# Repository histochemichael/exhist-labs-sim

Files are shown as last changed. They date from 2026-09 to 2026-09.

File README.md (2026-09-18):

# ExHist Labs Simulation

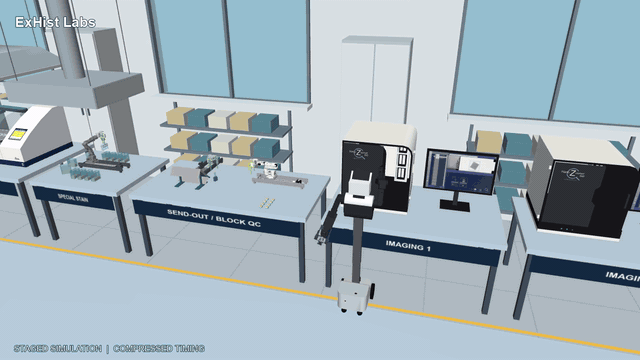
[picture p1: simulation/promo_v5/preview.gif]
ExHist Labs — looping 60-second lab promo


[Watch/download the full-quality video](simulation/promo_v5/ExHist-Labs-Promo-60s.mp4) · [Replay and QC details](simulation/promo_v5/README.md)

The preview loops through the full 60-second promo. If it is paused, check your
[GitHub animated-image settings](https://docs.github.com/en/account-and-profile/how-tos/account-settings/managing-accessibility-settings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).

A CAD-based histology laboratory in MuJoCo, with LeHisto stations, Nori A3, incubators, staining/coverslipping, scanning, and slide send-out/QC.

**Research simulation / development snapshot.** The live demo validates a bounded LeHisto rack loop. The promo is staged kinematic playback, not a physically validated autonomous lab.

## Browse by purpose

| Looking for | Open |
| --- | --- |
| Install, run, and tour every station | [Full illustrated guide](simulation/README.md) |
| Latest 60-second video and portable playback | [Revision 5: close-ups and continuous departure](simulation/promo_v5/) |
| Promo instructions and limitations | [Promo guide](simulation/docs/PROMO.md) |
| CAD STEP/STP and STL files | [CAD folder](simulation/cad/) |
| Static asset XMLs | [Asset models](simulation/models/assets/) |
| Station and asset pictures | [Image gallery](simulation/docs/images/) |
| Original/pinned source assets | [Source folder](simulation/source/) |
| Simulator mesh and texture assets | [Runtime assets](simulation/assets/) |
| Validation and distribution notes | [Validation record](simulation/docs/DISTRIBUTION_VALIDATION.md) |
| Repository organization | [Folder map](docs/REPOSITORY_LAYOUT.md) |
| Licensing and attribution | [License notice](simulation/LICENSE-NOTICE.md) |

## Run

From the repository root, using the documented Windows/Conda setup:

```powershell
cd simulation
conda env create -f environment.yml
conda activate exhist-sim
python tools/unpack_assets.py
python tools/check_install.py
python lab_rail_loop.py
```

After setup, `./launch.ps1` from the repository root starts the live demo. The viewer starts paused; press Space to run. See the full guide for controls and the separate Nori equipment-access environment.

The simulation bundle stays under `simulation/`, with the latest promo, portable
scene/playback, looping preview and scoped evidence grouped in `simulation/promo_v5/`.
Revision 5 includes the left parallel/right stock-claw swap, upright rack
transfers, gripper close-ups, smooth camera, supplied scanner screen and logo,
and Nori continuing away through the ending. The previous v4 bundle remains
available as history; the separate contact-tested live LeHisto demo is unchanged.

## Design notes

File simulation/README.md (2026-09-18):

# ExHist Labs Simulation

A CAD-based histology laboratory in MuJoCo: LeHisto sorting and special staining, Nori A3 handling, Quincy incubators, Leica staining/coverslipping, Hamamatsu scanning, and slide send-out/QC.

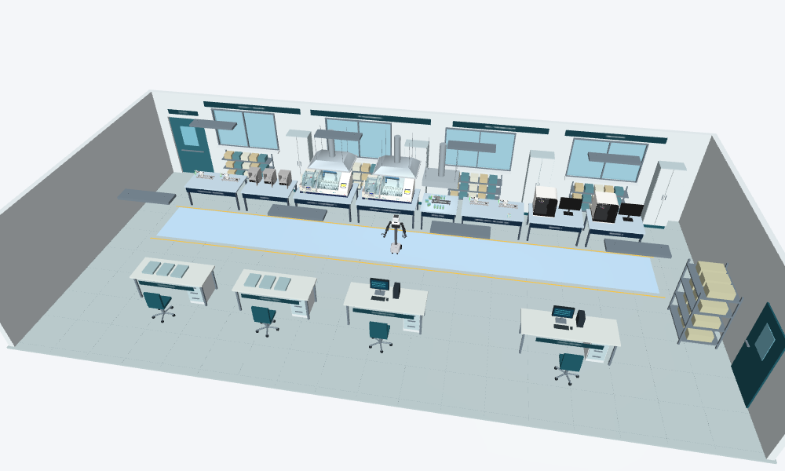
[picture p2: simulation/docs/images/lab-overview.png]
ExHist Labs — current complete room layout


**Research simulation / development snapshot. The full lab is not yet physically operational.** The current default demo runs the contact-driven, eleven-bath LeHisto rack loop in the complete room. Other stations and Nori are held visual context in that mode. No hardware commands are issued.

## Start here

- [Install and run](#install-and-run)
- [Station tour](#station-tour)
- [Asset gallery and downloads](#asset-gallery-and-downloads)
- [What is tested](#validation-and-limitations)
- [CAD and file conventions](docs/CAD_AND_ASSETS.md)
- [Licensing and attribution](LICENSE-NOTICE.md)

## Install and run

### Latest: 60-second promo with gripper close-ups

Watch the latest ExHist Labs promo

[Watch/download the 60-second MP4](promo_v5/ExHist-Labs-Promo-60s.mp4) · [Replay instructions and evidence](promo_v5/README.md)

In revision 5, Nori uses the original **right claw** for equipment access and the **left parallel gripper** for the upright rack. The loaded scanner, supplied PC screenshot, recorded LeHisto folder/sorting/staining work, top-right rack-handling close-ups and exact logo ending are included. Nori continues rolling away through the fade. The promo ovens have **120 mm extra upper clearance** as a modified concept, not stock Quincy dimensions. This is staged kinematic playback; see the scoped evidence and limitations in the promo guide.

The authored cut kept rack tilt below **0.018 degrees** and passed scoped geometric checks at all **1,800 frames**. This is **staged kinematic playback**, not a full-lab contact-physics result or proof of real slide retention. Fresh packaged checks and preserved author evidence are linked in the guide.

### Live laboratory scene

Windows 64-bit is the tested platform. Use **Python 3.10, MuJoCo 3.4.0 and PlaCo 0.9.20** for the live LeHisto loop. A desktop OpenGL-capable display/driver is needed for the viewer and screenshot rendering. Fusion is **not** required to run the simulation. No ROS, robot, camera or hardware connection is required.

Clone this repository (or download and extract its ZIP), then open a terminal in its `simulation/` directory. All commands in this guide run from that directory:

```powershell
conda env create -f environment.yml
conda activate exhist-sim
python tools/unpack_assets.py
python tools/check_install.py
python lab_rail_loop.py
```

The Conda environment gets the Windows PlaCo build from conda-forge. Other Python dependencies are pinned in [requirements.txt](requirements.txt). These versions were tested in an existing Windows environment; the environment file is a reproducible setup specification, not a claim of testing every fresh OS installation.

The viewer starts **paused**. Press **Space** to start/pause, **L** for LeHisto detail, **O** for the whole room, **1–8** for stations, and **+ / −** for playback speed. Close the window to exit. Initial loading can take a while because detailed CAD meshes are compiled.

PowerShell alternative, after activating the environment:

```powershell
./launch.ps1                       # live LeHisto loop
./launch.ps1 -Mode layout          # static/kinematic CAD inspection
./launch.ps1 -Mode hold            # readiness-hold view
```

If PowerShell blocks scripts, use the direct Python commands; changing system execution policy is unnecessary. The launcher uses the active environment's Python, not an author-specific installation path.

### Individual asset inspection

Each generated asset XML is a **static inspection model**, not a replacement for articulated machine physics. For example:

```powershell
python -m mujoco.viewer --mjcf models/assets/rack24.xml
```

### Nori equipment doors/drawers — separate environment

The original Nori access evidence used **MuJoCo 3.12.0 / Python 3.12**, not the live-loop engine. Keep these environments separate:

```powershell
conda create -n exhist-access -c conda-forge python=3.12 pip
conda activate exhist-access
python -m pip install -r requirements-access.txt
python tools/unpack_assets.py
python access_viewer.py --kind quincy
```

Kinds: `quincy`, `s60`, `st_load`, `st_unload`, `cv_load`, `ts_drawer`. These are **fixed-dock, actual-arm contact experiments**; the base is anchored and door/drawer dynamics are provisional. They are not complete mobile rack-transfer sequences. Keep the guards enabled.

### Headless checks

In `exhist-sim`:

```powershell
python tools/check_install.py
python -m unittest test_lab_rail_loop -v
python lab_rail_loop.py --validate
```

The last command reruns all eleven transfers and writes new `rail_loop_lab*.json` evidence. It may take several minutes or longer. It is not a whole-lab validation. Do not commit regenerated traces without inspecting the result. Existing files are versioned, so use a clean checkout or separate copy if preserving the packaged evidence matters.

### Troubleshooting

- **Missing file / compressed asset:** run `python tools/unpack_assets.py`. The script verifies SHA-256 and refuses to overwrite modified files. Large STEP/trace files are gzip-compressed to avoid normal GitHub file-size limits; Git LFS is not required.
- **Wrong MuJoCo version:** activate `exhist-sim` for the LeHisto loop, `exhist-access` for Nori access. Do not upgrade the physics engine and assume prior evidence still applies.
- **PlaCo import/DLL problem on Windows:** use the supplied Conda environment rather than assuming a Windows pip wheel exists. See [PlaCo installation documentation](https://placo.readthedocs.io/en/latest/basics/installation_pip.html).
- **OpenGL/display error:** use a local graphical desktop and working graphics driver. Headless rendering setup is platform-specific and is not bundled.
- **Pinned dependency/hash mismatch:** restore the matching repository revision or deliberately rebuild and revalidate. Do not disable integrity checks.
- **Neutral-pose adjacent-link warnings from PlaCo:** these are emitted by the imported IK model at initialization. The live loop has separate contact/failure guards; these messages are not a certification that all self-collisions are resolved.

## Station tour

These are actual renders of the packaged current model, not AI-generated concept images. The images show layout, not proof that every interaction works.

| Station | Purpose / equipment |
| --- | --- |
| Protocol sorting | Two LeHisto robots; protocol grouping and handled rack staging. |
| Baking | Three Quincy incubators. |
| Routine stain + coverslip 1 and 2 | Two Leica ST5020/CV5030 workstations with overhead canopies. |
| Special stain | One LeHisto, eleven matching containers, 25.4 mm inserts and canopy. |
| Send-out / block QC | Two LeHisto robots, slide folders and embedded cassette blocks. |
| Imaging 1 and 2 | Two Hamamatsu NanoZoomer S60 scanners with PCs. |
| Support / finished bench | Preparation, general work, documentation and digital-review bays. The general-work bench is the planned finished-folder destination. |

### Protocol sorting

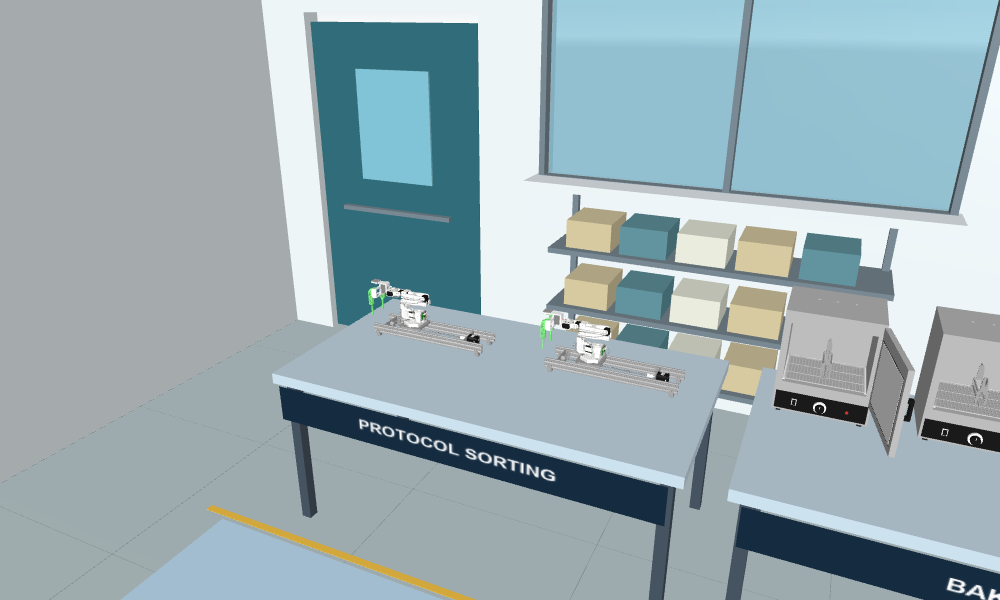
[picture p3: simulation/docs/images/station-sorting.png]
Protocol sorting station


Two LeHisto stations and rack staging. Populated-rack sorting and Nori handoffs are still under development.

### Baking

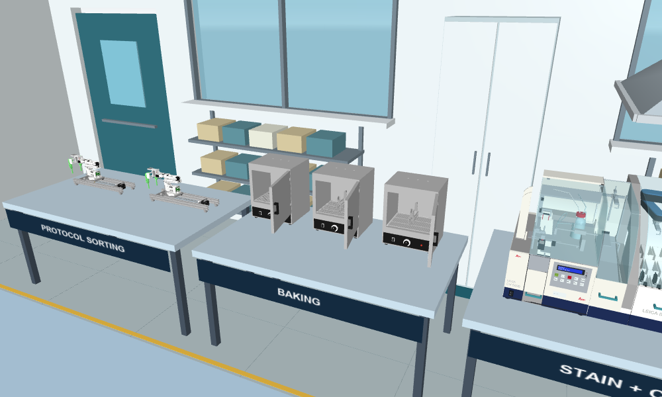
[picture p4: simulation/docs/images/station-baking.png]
Baking station


Three Quincy incubators. Doors are physical in isolated access tests; thermal processing is not modeled.

### Routine stain + coverslip 1

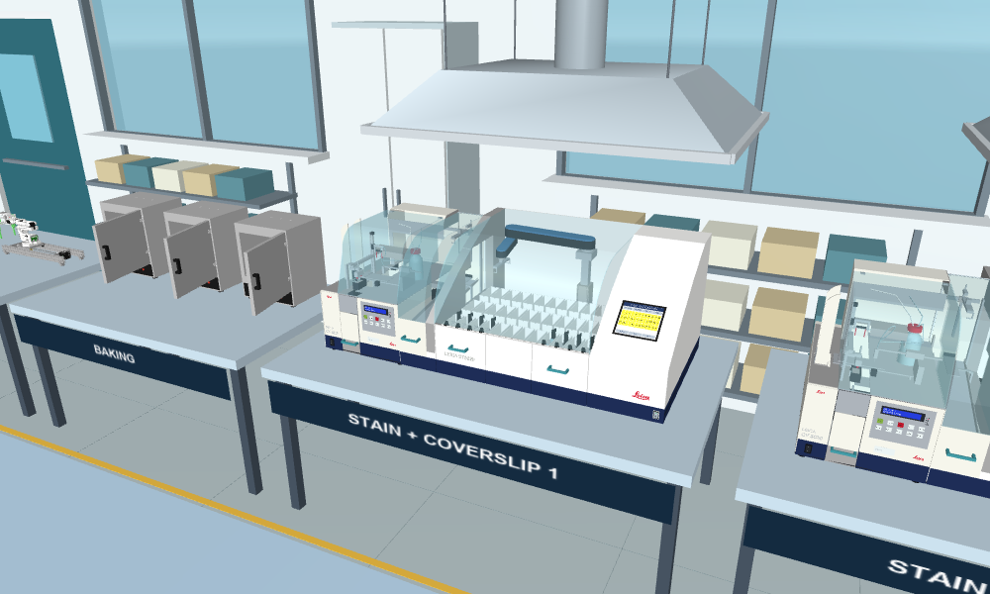
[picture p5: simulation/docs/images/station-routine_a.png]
Routine stain + coverslip 1 station


Leica ST5020/CV5030 workstation, access pulls and canopy. Inspection glazing lets the internals remain visible.

### Routine stain + coverslip 2

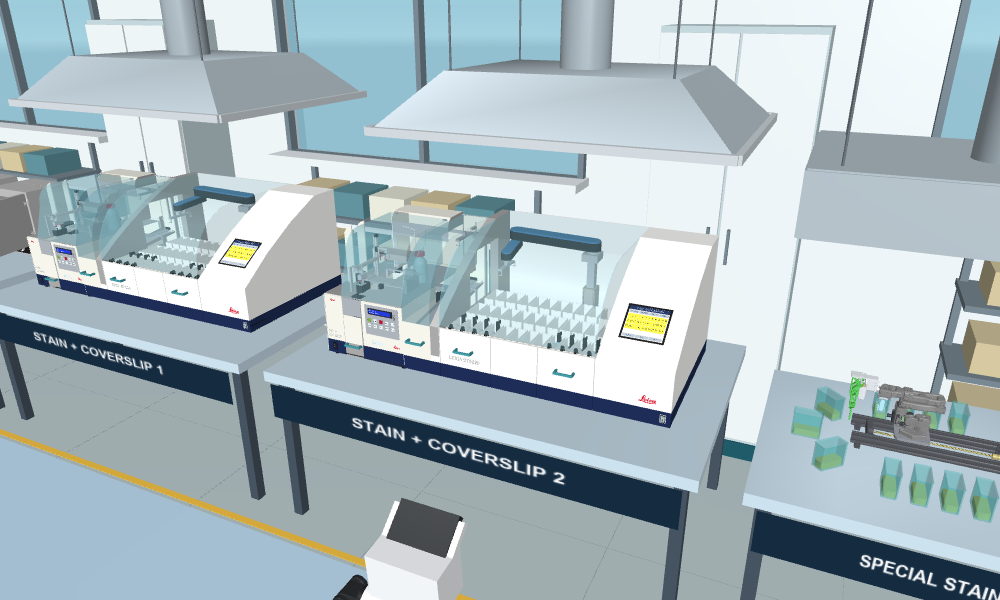
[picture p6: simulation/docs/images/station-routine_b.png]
Routine stain + coverslip 2 station


Second routine-processing bay. Internal articulation does not establish contact-validated payload transfer.

### Special staining

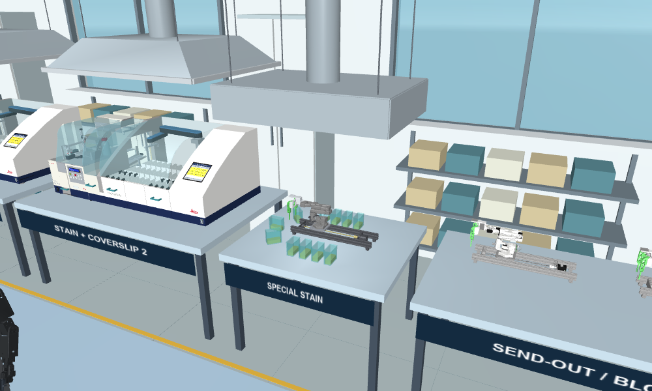
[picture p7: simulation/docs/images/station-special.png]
Special staining station


Live eleven-bath route: 1 → 2 → … → 11 → 1, original gripper, one-inch risers and bounded tabletop.

### Send-out / block QC

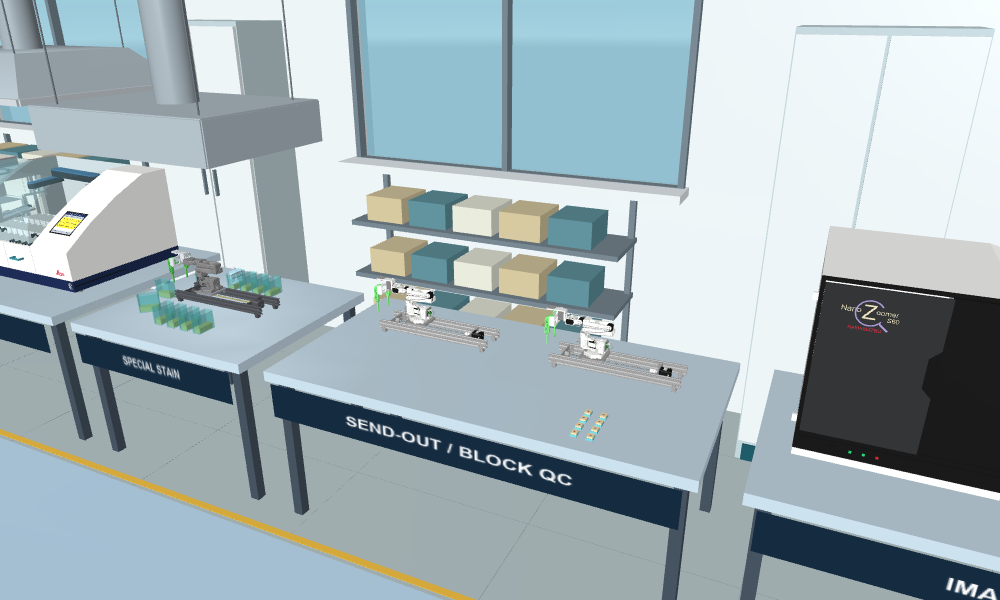
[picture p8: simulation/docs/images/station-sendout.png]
Send-out / block QC station


Two LeHisto arms, folder workspace and cassette-block QC. Folder loading/closing/carrying is not yet physically validated.

#### New: 45-degree QC folder cradle (selectable layout)

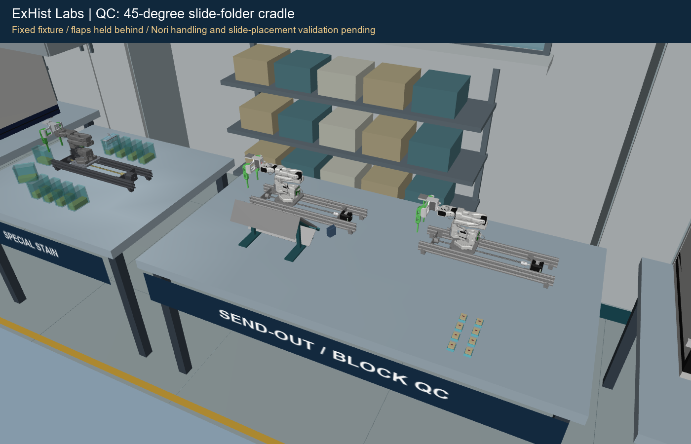
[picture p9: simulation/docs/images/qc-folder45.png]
QC folder cradle in the lab


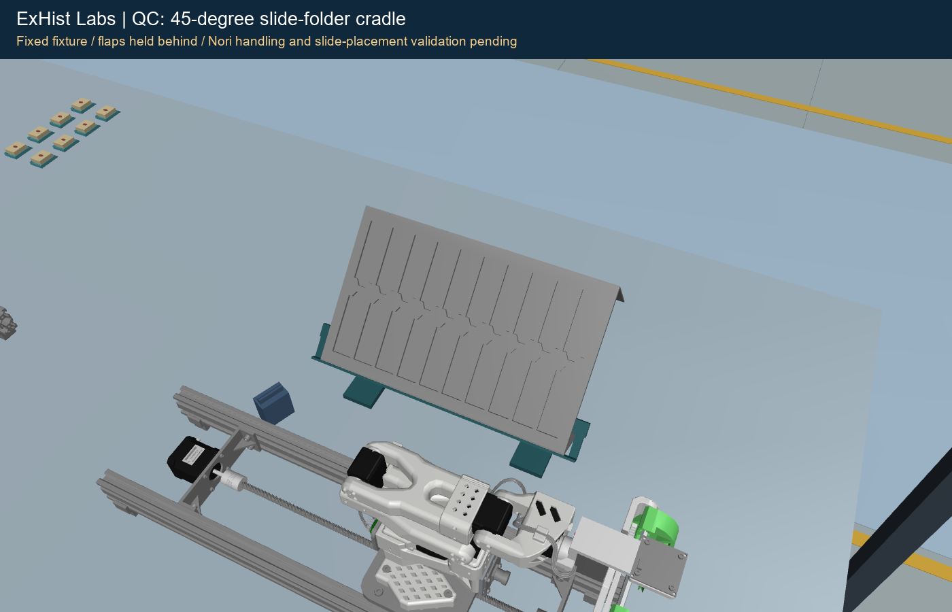
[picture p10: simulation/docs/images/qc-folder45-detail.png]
Folder pockets viewed from the LeHisto side


The pinned concept places a 20-pocket folder on a fixed, 45-degree presentation cradle in front of the left QC LeHisto. Its cover flaps are held behind the tray; the feet sit on the 800 mm bench. Empty side-access volumes are reserved for Nori's left arm, but are **not certified gripper envelopes**. No second Nori has been added. Nori need not continuously hold the folder in this fixture concept.

```powershell
python qc_folder_cradle.py                    # held whole-lab QC inspection
python lab_rail_loop.py --qc45                # live special-stain loop + held QC layout
python qc_folder_cradle.py --check            # scoped static layout checks
python -m unittest test_qc_folder_cradle -v
```

Press **6** in the live-loop viewer for QC. This optional composition preserves the existing tested base XML and historical evidence. The new 45-degree slide-placement controller is still being tested separately and is **not imported or claimed passed**. Passive folder docking, Nori reach/grasp/transfer, fasteners, stiffness, stability, flap closing and loaded retention remain unvalidated.

[Layout and assumptions](docs/QC_FOLDER45.md) · [stand STL, mm](cad/stl/Folder-Stand-45-Assembly.stl) · [standalone folder/cradle XML, m](models/assets/qc_folder45.xml) · [scoped check results](qc_folder45_validation.json)

### Imaging 1

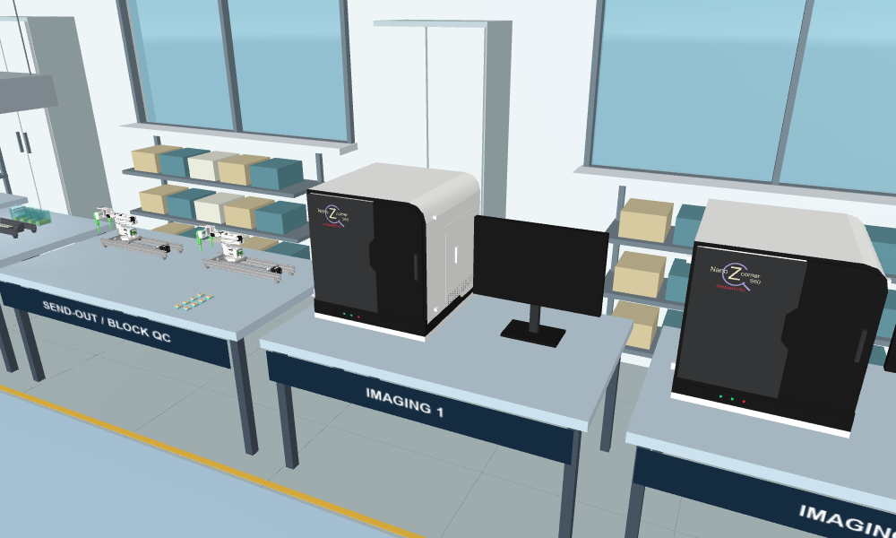
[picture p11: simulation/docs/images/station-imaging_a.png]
Imaging 1 station


NanoZoomer S60 and PC; scanner cassette interfaces and Nori insertion need further integration.

### Imaging 2

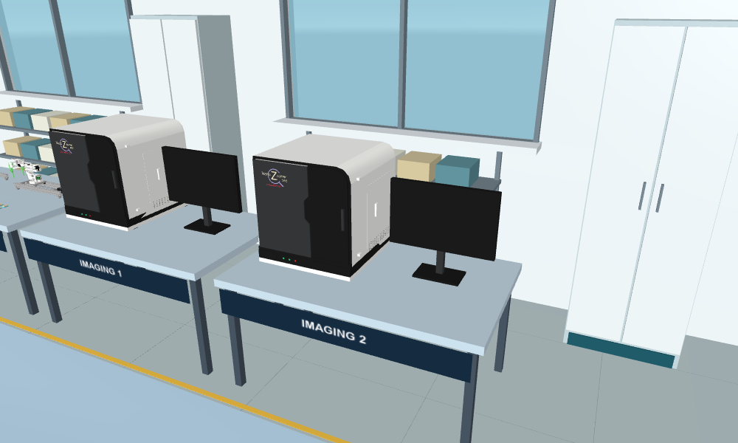
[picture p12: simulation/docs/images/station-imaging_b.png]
Imaging 2 station


Second scanner and PC with the same development limitations.

### Nori A3 and the surrounding lab

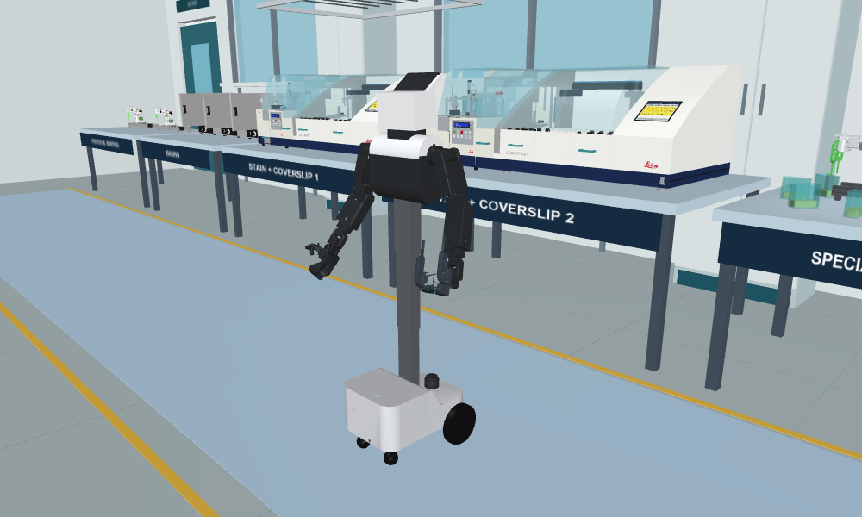
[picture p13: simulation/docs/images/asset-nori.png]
Nori A3 in the current laboratory stance


The historical base environments retain the stock left claw and parallel histology gripper on the other arm. **The latest [v5 promo scene](promo_v5/scene.xml) swaps these: left parallel tool, right stock claw.** Its raised inspection posture keeps the shoulders above the 800 mm benches. Gripper grooves are user-tested hardware geometry; complete contact-force grasp/transfer validation remains separate. Nori’s original source model is [bundled here](source/nori/Nori%20with%20parallel%20histo%20gripper.xml), with [mesh files](assets/nori) and [license/limitations](licenses/nori/NOTICE). **No Nori STEP manufacturing CAD was supplied; none is fabricated from these meshes.**

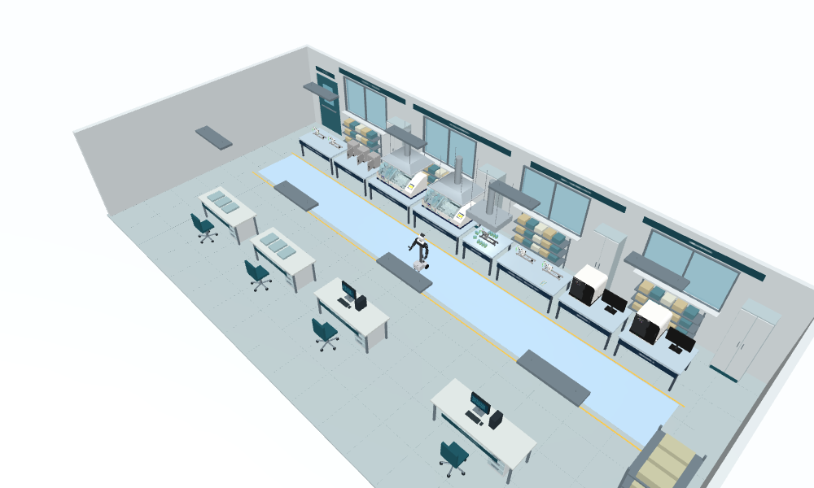
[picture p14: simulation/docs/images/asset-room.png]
Cabinets, shelves, work bays, chairs, doors, windows and PCs


The architectural context includes four windows, two doors, four tall cabinets, five shelving bays, four extra work tables, four chairs and two additional PCs. The eight process benches, hoods, aisle markings, furniture and signage are procedural geometry in [lab_room.py](lab_room.py), [build_scene.py](build_scene.py), and the main XMLs. They are static scene props; door swing, furniture mechanics and fume extraction are not validated. Canopies are layout concepts, not ventilation designs.

## Asset gallery and downloads

**STL exports below use millimetres; MuJoCo XML/OBJ geometry uses metres.** Original robot STLs keep their original scales, specified in their XML/URDF; do not apply the catalogue STL scale indiscriminately. Native CAD assemblies and simulation tessellations are different deliverables. See [CAD provenance and conventions](docs/CAD_AND_ASSETS.md).

### LeHisto v38

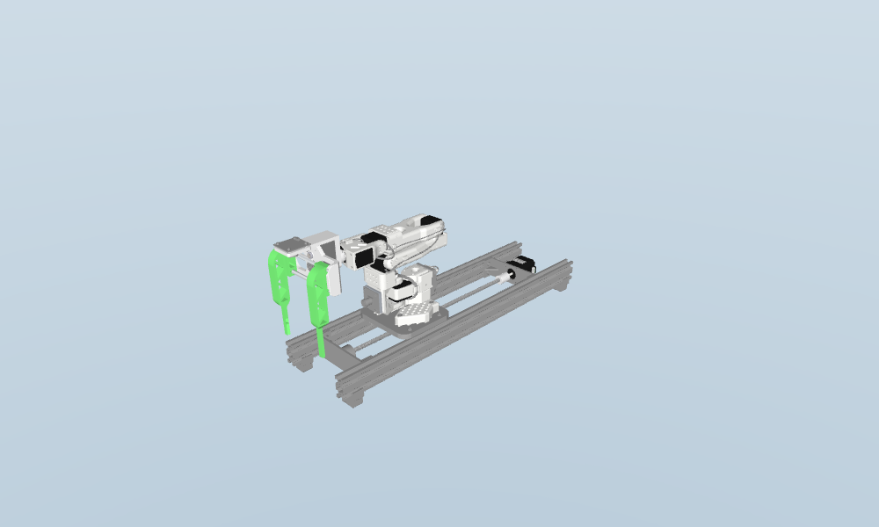
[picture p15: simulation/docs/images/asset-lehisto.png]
LeHisto v38


Rail-mounted SO-101 arm with the printed dual-groove slide/handle gripper and cameras.

[STL](cad/stl/lehisto.stl) · [Asset XML](models/assets/lehisto.xml) · [Source tessellation](assets/lehisto.json) · [STEP/STP](cad/step/lehisto-v38.stp)

### Quincy 10GC incubator

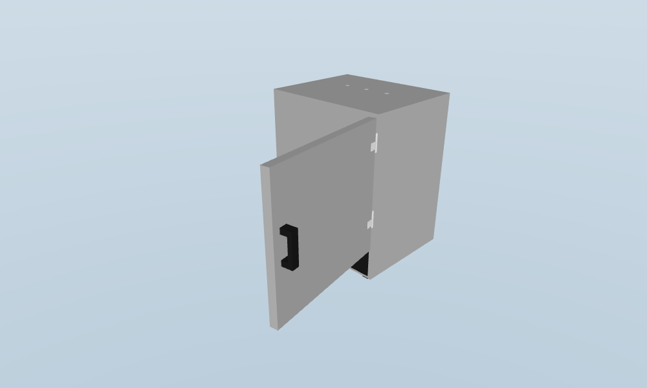
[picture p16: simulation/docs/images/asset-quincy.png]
Quincy 10GC incubator


Baking enclosure and swing door. Three instances sit on the baking bench.

[STL](cad/stl/quincy.stl) · [Asset XML](models/assets/quincy.xml) · [Source tessellation](assets/quincy.json) · [STEP/STP](cad/step/quincy-10gc.stp)

### Leica ST5020 + CV5030

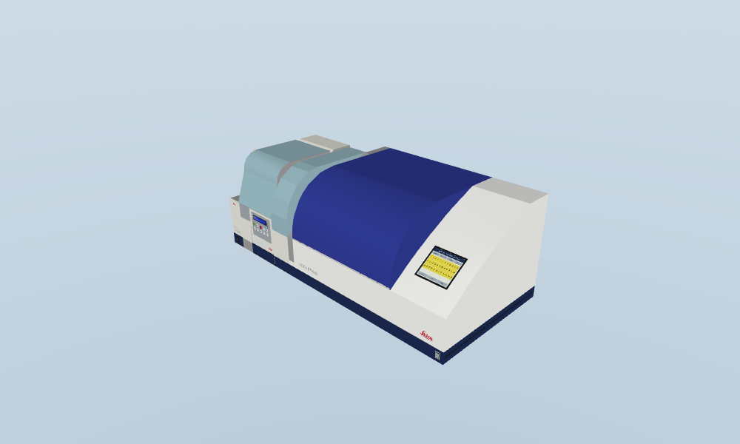
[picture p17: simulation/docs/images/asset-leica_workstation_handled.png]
Leica ST5020 + CV5030


Stainer, coverslipper and transfer station. CAD articulation and estimated internals are retained; transparent lids are a simulation inspection setting.

[STL](cad/stl/leica_workstation_handled.stl) · [Asset XML](models/assets/leica_workstation_handled.xml) · [Source tessellation](assets/leica_workstation_handled.json) · [STEP/STP (gzip)](cad/step/leica-workstation.stp.gz)

### Hamamatsu NanoZoomer S60

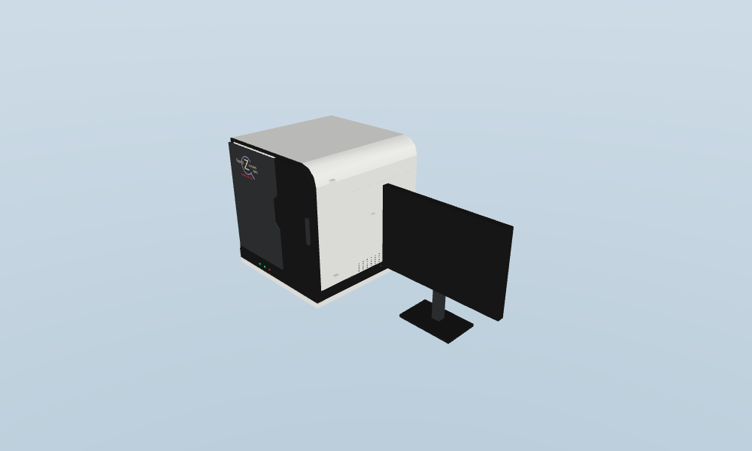
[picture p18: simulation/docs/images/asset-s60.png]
Hamamatsu NanoZoomer S60


Branded scanner assembly and PC. Scanner depth and carrier interfaces remain provisional.

[STL](cad/stl/s60.stl) · [Asset XML](models/assets/s60.xml) · [Source tessellation](assets/s60.json) · [STEP/STP](cad/step/nanozoomer-s60.step)

### 24-slide handled rack

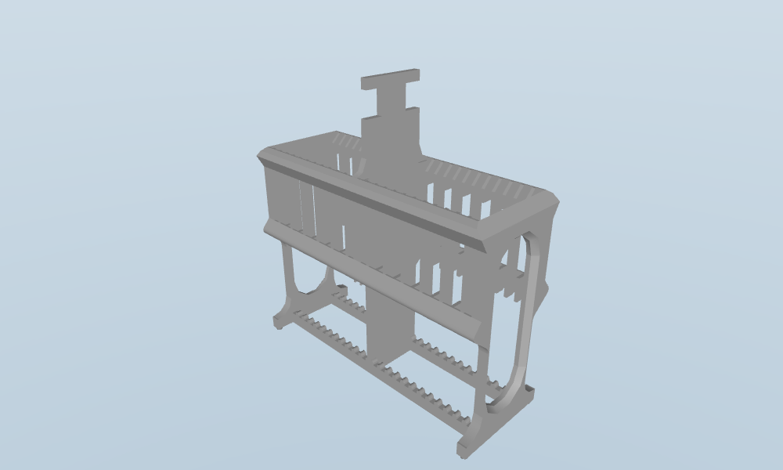
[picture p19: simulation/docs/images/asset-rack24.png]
24-slide handled rack


User-tested handle geometry; not interchangeable with the Leica or scanner carriers.

[STL](cad/stl/rack24.stl) · [Asset XML](models/assets/rack24.xml) · [Source tessellation](assets/rack24.json) · [STEP/STP](cad/step/slide-rack-24-with-container.stp)

### Matching 24-slide container

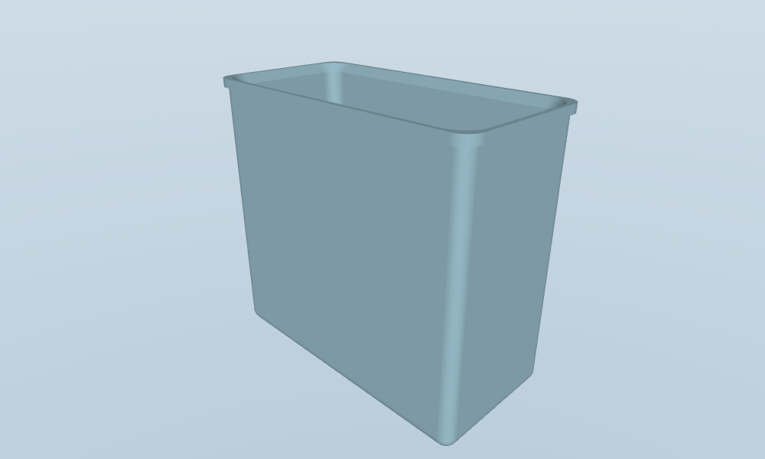
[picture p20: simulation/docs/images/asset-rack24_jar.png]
Matching 24-slide container


Actual companion vessel for the rack; eleven are arranged around the special-staining rail.

[STL](cad/stl/rack24_jar.stl) · [Asset XML](models/assets/rack24_jar.xml) · [Source tessellation](assets/rack24_jar.json) · [STEP/STP](cad/step/slide-rack-24-with-container.stp)

### 25.4 mm container insert

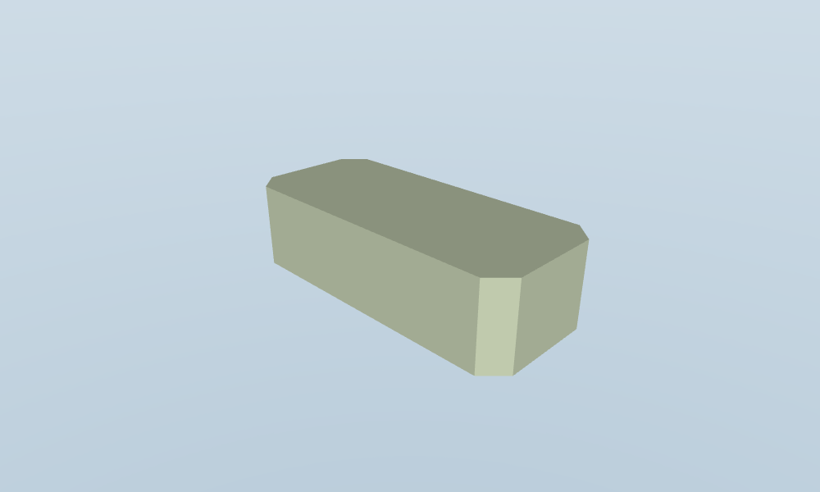
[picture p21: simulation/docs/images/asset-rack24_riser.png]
25.4 mm container insert


Removable one-inch support block. Material, fluid compatibility and immersion depth are unvalidated.

[STL](cad/stl/rack24_riser.stl) · [Asset XML](models/assets/rack24_riser.xml) · [Source tessellation](assets/rack24_riser.json) · [Parametric source](assets/rack24_riser_25p4mm.scad)

### Handled Leica staining rack

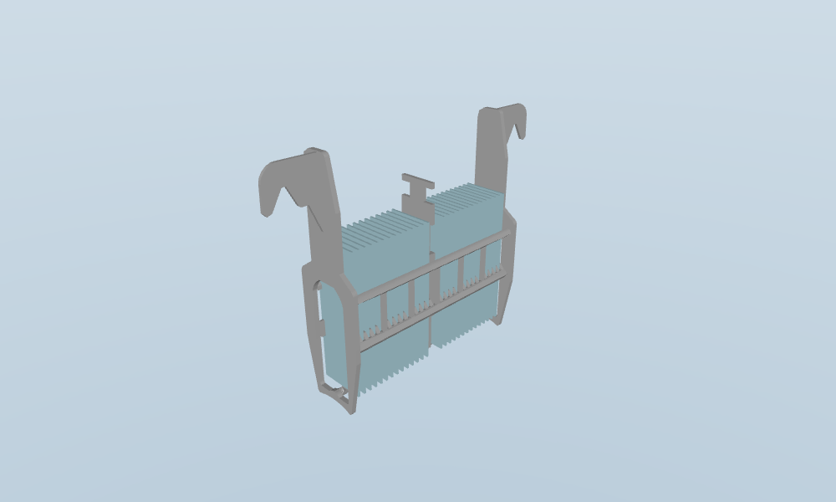
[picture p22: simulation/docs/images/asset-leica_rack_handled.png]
Handled Leica staining rack


Updated input rack with carrying handles. Native export captures the open Fusion document, including its unsaved local state.

[STL](cad/stl/leica_rack_handled.stl) · [Asset XML](models/assets/leica_rack_handled.xml) · [Source tessellation](assets/leica_rack_handled.json) · [STEP/STP](cad/step/leica-rack-handled.stp)

### CV5030 30-position output magazine

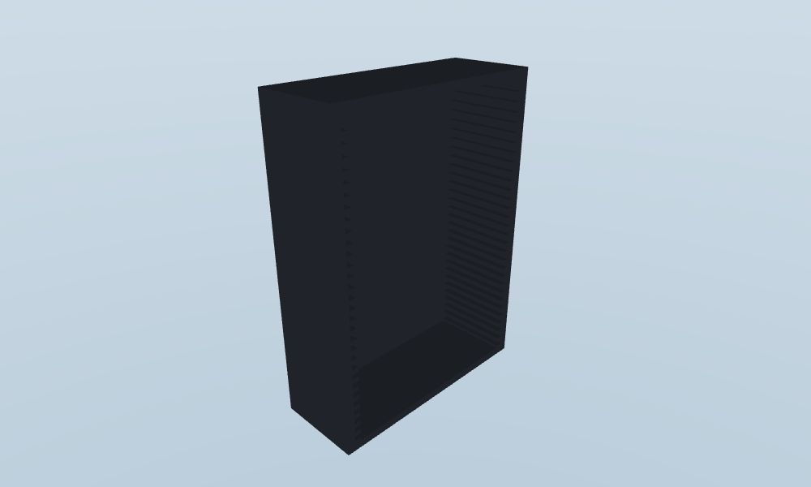
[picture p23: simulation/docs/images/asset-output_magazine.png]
CV5030 30-position output magazine


Output carrier for coverslipped slides. Automated removal and populated slide exchange are unfinished.

[STL](cad/stl/output_magazine.stl) · [Asset XML](models/assets/output_magazine.xml) · [Source tessellation](assets/output_magazine.json) · [STEP/STP](cad/step/cv5030-output-magazine-30.step)

### Scanner cassette

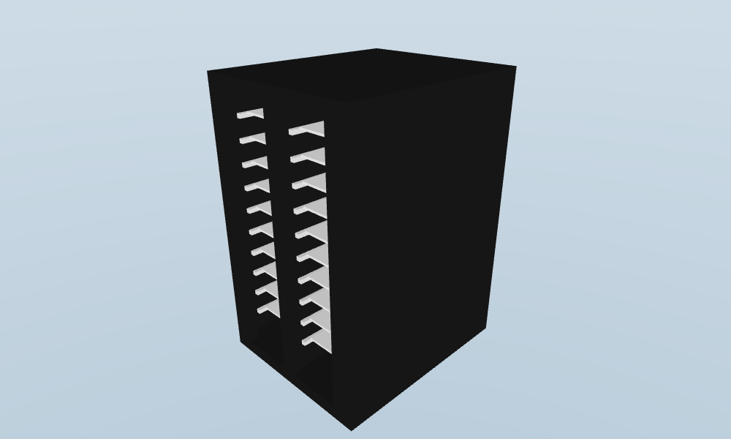
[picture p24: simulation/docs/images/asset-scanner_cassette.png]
Scanner cassette


S60-specific carrier. Its depth is explicitly provisional; this export does not establish slide/gripper clearance.

[STL](cad/stl/scanner_cassette.stl) · [Asset XML](models/assets/scanner_cassette.xml) · [Source tessellation](assets/scanner_cassette.json) · [STEP/STP](cad/step/scanner-cassette-provisional.stp)

### 20-place slide folder

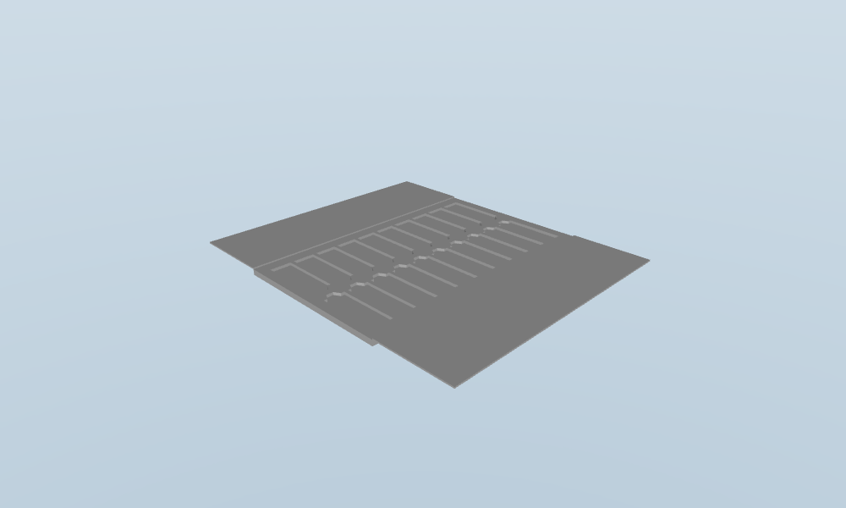
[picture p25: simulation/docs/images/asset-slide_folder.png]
20-place slide folder


Cardboard folder and cover flaps. Physical folding, loaded retention and left-hand transport remain unfinished.

[STL](cad/stl/slide_folder.stl) · [Asset XML](models/assets/slide_folder.xml) · [Source tessellation](assets/slide_folder.json) · [STEP/STP](cad/step/slide-folder-20.stp)

### Embedded cassette block

Embedded cassette block

Cassette, paraffin and tissue geometry for the block-QC work surface.

[STL](cad/stl/cassette_block.stl) · [Asset XML](models/assets/cassette_block.xml) · [Source tessellation](assets/cassette_block.json) · [STEP/STP](cad/step/embedded-cassette-block.step)

### Grippers, handles, slides and coverslips

Original gripper handle groove contact inspection

The top finger groove receives rack handles; the lower groove receives slides. The detailed LeHisto gripper/rail source meshes and joint descriptions are in [rail_loop_reference/source/robot](rail_loop_reference/source/robot). Nori's attachment meshes are in [assets/nori](assets/nori). [Drawer pulls v02](cad/step/drawer-pulls-v02.step) and the [Quincy stand-off pull](cad/step/quincy-pull-v01.step) are **unbuilt concepts**, not approved machine modifications. Slides, coverslips, support surfaces and fixture/contact proxies also appear as procedural geoms in the XMLs. The loaded rack in the current eleven-bath loop uses fixed slide visuals, **not individually free glass**.

### Procedural room asset kit

Bench, canopy, cabinet, shelf, chair, PC, entry door and window close-ups

These representative pieces are exported from the actual scene geometry. They are static visual models, not fabrication designs or mechanically validated furniture.

| Asset | STL | XML |
| --- | --- | --- |
| Process bench | [STL](cad/stl/bench.stl) | [XML](models/assets/bench.xml) |
| Special-stain canopy | [STL](cad/stl/canopy.stl) | [XML](models/assets/canopy.xml) |
| Storage cabinet | [STL](cad/stl/cabinet.stl) | [XML](models/assets/cabinet.xml) |
| Shelf bay and boxes | [STL](cad/stl/shelves.stl) | [XML](models/assets/shelves.xml) |
| Task chair | [STL](cad/stl/chair.stl) | [XML](models/assets/chair.xml) |
| PC workstation | [STL](cad/stl/pc.stl) | [XML](models/assets/pc.xml) |
| Entry door | [STL](cad/stl/entry-door.stl) | [XML](models/assets/entry-door.xml) |
| Observation window | [STL](cad/stl/window.stl) | [XML](models/assets/window.xml) |

## Files and data

| Location | Contents |
| --- | --- |
| `exhist_rail_loop.xml` | Current complete-room model with live special-stain station and held lab context. |
| `exhist_operational.xml` | Articulated development scene / readiness workbench. |
| `exhist.xml` | Static/kinematic lab inspection layout. |
| `assets/` | Actual mesh, texture, tessellation and kinematic assets used by the lab. |
| `models/assets/` | Individual static asset XML viewers and their meshes. |
| `cad/step/` | Native STEP/STP exports; large workstation file is losslessly compressed. |
| `cad/stl/` | Consolidated millimetre STL exports of the catalogued CAD assets. |
| `source/` | Bundled source Nori XML and mesh dependencies. |
| `rail_loop_reference/` | Pinned reference controller, URDF, scene, meshes and evidence. |
| `docs/images/` | Rendered station/asset gallery. |
| `docs/portability-validation.json` | XML-parameter and compiled-dynamics comparison after path relocation. |
| `docs/DEVELOPMENT_HISTORY.md` | Historical author notes; older claims/launch paths do not override this README. |

Authoring/export scripts remain for provenance and development. Some historical Fusion/film/rebuild helpers refer to the author's external projects and are **not portable entry points**. Running the delivered XMLs and documented viewers does not require those external projects. Do not blindly regenerate source snapshots from other tasks.

## Validation and limitations

The packaged copy passed a fresh **11/11 transfer run** and **20 targeted regression tests**. See [distribution validation](docs/DISTRIBUTION_VALIDATION.md) for versions, measurements and scope.

The original lab loop completed all eleven contact-driven rack transfers. A fresh packaged-copy run and its scope are recorded in [rail_loop_lab_validation.json](rail_loop_lab_validation.json). [LAB_RAIL_LOOP_RESULTS.md](LAB_RAIL_LOOP_RESULTS.md) describes the original integration evidence, including its export-recovery provenance. [STABILITY_VALIDATION.md](STABILITY_VALIDATION.md) describes separate fixed-dock access/passive-object tests. Those are distinct experiments, not an end-to-end lab acceptance test.

The portability check compares all non-path XML parameters and 420 numerical model arrays per model. Resource-path buffers and MuJoCo-derived convex-hull representation differences are reported separately. No controllers, joint limits, physical forces or contact rules were relaxed to package the demo.

**Still unfinished:** coordinated Nori navigation/docking and handoffs; populated carrier exchange; CV5030 output-rack extraction; scanner insertion/removal; complete physical folder loading, closing and transfer; room-wide collision coverage. Fluids, chemistry, glass breakage, optical scanning, medical performance and hardware safety are not validated.

This repository is a development workbench, **not** a turnkey autonomous lab, learned policy, manufacturer-certified digital twin, medical device, or authorization to operate equipment.

[Licensing / attribution / noncommercial Nori restrictions](LICENSE-NOTICE.md)

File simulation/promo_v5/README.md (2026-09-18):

# ExHist Labs promo — revision 5

Looping 60-second promo

[Watch/download the full-quality MP4](ExHist-Labs-Promo-60s.mp4) — 60 seconds,
1280 × 720, 30 fps. The GIF loops indefinitely; GitHub may pause animated images
when a viewer has reduced-motion or autoplay-disabled settings.

## What's in this revision

- Left parallel slide/rack gripper; original right claw for doors and drawers.
- Loaded scanner with 60 individual slide meshes and the supplied PC screenshot.
- Recorded LeHisto folder placement, slide sorting and special-stain background work.
- Upright oven-to-stainer rack transfer; oven and drawer close afterward.
- Fading top-right close-ups of rack pickup and stainer placement/release.
- Stainer fork deposits into the first rear vessel; Nori keeps rolling away
  through the fade into the supplied teal/black logo.

## Replay locally

Use the repository's documented Windows `exhist-sim` environment (MuJoCo 3.4.0),
then from `simulation/`:

```powershell
python promo_v5/render.py --check
python promo_v5/render.py
```

The second command writes `promo_v5/rerendered.mp4`; it does not overwrite the
published video. Desktop OpenGL is required. All scene resources are repository
relative; no author workspace, camera connection or hardware is needed.
`playback.npz` contains the exact 1,800 output-time joint/mocap/background poses
and both cameras, not a controller or training policy. Existing STEP/STL source
assets remain under `../cad/`, `../assets/` and `../source/`.

## Evidence and limits

- [Original sampled geometry audit](evidence/author-sequence-solid-audit.json):
  zero unintended intersections in its scoped 1,800-frame checks; maximum
  loaded rack tilt 0.008287 degrees.
- [Tool-swap audit](evidence/author-swap-mechanics-audit.json): original joint
  limits, mount frames, printed grooves and jaw coupling preserved.
- [Packaging equivalence](evidence/portability.json): resource paths changed,
  but compiled geometry, joint and inertia arrays match the author model.
- [Packaged replay check](evidence/packaged-render-check.json): rendered-frame
  comparisons, MP4 duration, GIF duration and indefinite-loop metadata.
- [Author delivery verification](evidence/author-delivery-gripper-closeups-rollaway-verification.json).

**Staged kinematics / compressed timing, not physically validated autonomy.**
Objects use prescribed poses/attachments. These checks do not certify grasp
forces, slip, actuator torque/speed, wheel-contact dynamics, passive-door forces,
whole-room continuous collision avoidance, hardware safety or actual throughput.
The oven is a user-authorized taller simulation concept (+120 mm upper headroom),
not manufacturer-certified dimensions or an updated manufacturing STEP.
Background folder work replays one previously tested pocket placement, not a
complete 20-slide folder. Original author reports are preserved as provenance;
they are not relabeled as newly executed packaged physical tests.

The prior v4 bundle remains available at `../promo_v4/` for history.

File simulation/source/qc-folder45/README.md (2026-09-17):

# Pinned Final QC Inputs

Copies from LeHisto commit d6da8e09789b35e5a1595b4da6a9ddd3871c7cfe (2026-09-16). Final folder center [0.026, -0.240, 0.075] m, 45-degree tray, covers held 100 degrees behind. Source holder [0.240, -0.100, 0.0127] m at 67.38-degree yaw.

`folder45.py` is builder provenance only; imports are not packaged to run here. `folder_slide_45.xml` contributes only the fixed folder, stand and source-holder geometry. `folder_stand_45.json` defines the ten-body stand. `slide_folder.json` is the original CAD tessellation.

Matching stand STEP, Fusion archive and millimeter STL are in `../../cad`. Hashes are recorded in `../../qc_folder45_layout.json`. LeHisto's standalone one-pocket dynamics passed; this lab integration is static context only, not Nori or lab slide-placement validation. Do not run the source builder to mutate another task.

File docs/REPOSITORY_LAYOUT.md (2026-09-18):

# Repository layout

The top level is a short entry point rather than hundreds of development files.

```text
README.md              Start here: downloads, gallery, installation
launch.ps1             Launch from the repository root
docs/                  Repository navigation and organization checks
simulation/            Self-contained simulation and historical evidence
  README.md            Full illustrated station guide and commands
  cad/                 STEP/STP, STL and native design assets
  models/assets/       Standalone static inspection XML models
  assets/              Runtime meshes and textures
  source/              Pinned source models and component provenance
  licenses/            Upstream license notices
  docs/                Station images, asset catalog, validation guides
  promo_v5/            Latest MP4, looping GIF, portable scene/playback and evidence
    background-assets/ Recorded folder-rig meshes
    evidence/          Author provenance and packaged replay verification
    images/            A few selected review frames
  promo_v4/            Historical promo, playback and scoped evidence
  rail_loop_reference/ Pinned LeHisto loop implementation and data
  tools/               Installation, unpacking and publication utilities
```

The loose files formerly at the root are now inside `simulation/`. Its Python modules, scene XMLs and historical output files intentionally retain their relative positions in this first organization pass: many experiments load neighboring traces and models by name. This avoids rewriting tested simulation behavior merely to change GitHub's landing page.

## Existing command migration

Run existing guide commands **from `simulation/`**, or use the new root launcher. All links within the full illustrated guide remain relative to that bundle. No CAD geometry, trace, model or video was regenerated for this move.

For example:

```powershell
cd simulation
python tools/unpack_assets.py
python -m unittest test_lab_rail_loop test_qc_folder_cradle -v
```

The root `.gitignore` excludes restored large assets at their new locations. Tracked gzip archives and their SHA-256 manifest remain inside the simulation bundle. Use `simulation/tools/unpack_assets.py` to restore them, not Git LFS.

## Organization checks (2026-09-17)

- Before documentation updates, all 1,977 relocated tracked files matched the Git blob hashes from `df662f0` exactly. No simulation code, CAD, XML, image, video or trace changed.
- All four compressed assets restored/verified against their existing SHA-256 manifest.
- Three main MuJoCo scenes compiled, and the live LeHisto controller initialized successfully from the new location.
- All 13 existing loop/QC regression tests passed.
- New navigation links and existing publication-guide links resolved; common credential-pattern and oversized-file checks passed. This is not a comprehensive security audit.
- The existing neutral-pose adjacent-link warnings remain; this organization pass does not claim new physical validation or rerun the full lab workflow.

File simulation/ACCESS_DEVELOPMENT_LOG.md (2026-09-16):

# Access controller development — nominal fixtures completed

Final current evidence is in `ACCESS_VALIDATION.md` and `access_final_validation.json`.
All six nominal contact cycles pass on one common source version. The missed
Quincy handle reports NO_GRASP with zero door travel; the jammed stainer drawer
stops after 1.534 mm. No passive equipment has an actuator, weld or live pose
setter. This completes isolated fixed-dock access, not full-lab transfers.

Final corrections after the historical notes below: 0.25 ms physics step,
smooth effort-ramped claw closure/release, a software empty-close stop, a narrow
proximal gear/socket proxy exemption, planned hinge approach with reduced wrist
rotation, actual contact-wrench overload monitoring and measured closed-stop
recognition. Drawer motors retain 4 Nm arm caps; no force limits were increased.
Quincy uses the separately exported proposed pull concept. Its original handle
and all source machine designs are unchanged.

The proposed fixed head-side camera in the review is editorial/simulation
mount geometry, not calibrated hardware. Lab route guards remain enabled.

## Historical debugging notes (superseded by the final reports)

The active request is to finish physical door/drawer cycles. Do not infer full-lab transfer readiness from these fixtures.

`equipment_access.py` uses the actual seven-joint left arm and force-limited lift. Equipment is passive: no live door pose assignments, door actuators, welds or mocap attachments. All imported arm effort caps remain 4 Nm. Current pull ceiling is 3 N and left-claw torque ceiling 1.5 Nm. Dynamics remain explicitly provisional.

Important corrections made during development:

- Isolated only the spurious contacts between nested telescopic lift tube bounding boxes. External tube collisions remain enabled.
- Planned whole-stroke arm/lift branches, corrected phase-transition timeout accounting and seeded redundant IK from its planned branch.
- Preserved the actual left-claw CAD recesses across both axial length and width. Earlier whole-width convex slices filled recesses.
- Selected the flat inner finger region: nominal grasp depth 114 mm for pulls, 116 mm for scanner handle. Original visual CAD and tested printed slide/rack gripper remain unchanged.
- Made acquisition hold its pose instead of chasing a handle displaced during closing; require bilateral contact, alignment and low equipment velocity.
- Found excessive soft joint-stop penetration under constant claw effort. Joint limits and the left finger mimic now use stiff constraints, with explicit violation monitoring. Old successes require revalidation after this correction.

Four drawer types completed cycles with the refined contact geometry before the latest stop/mimic and planned-branch corrections: ST5020 load/unload, CV5030 load and TS5025 transfer. Scanner and incubator remain under active revalidation. Read the latest reports; do not claim all six pass until the final common-source regression run does so.

The OEM Quincy handle mounting feet physically interfere with the original left claw. `quincy_offset_pull.py` is a separate **proposed** 35 mm stand-off, 10 mm diameter, 100 mm tall round pull with 80 mm clear space between supports. Its 80 g mass is assumed; mounting/fastening, temperature compatibility and load capacity are not validated. No original Fusion design has been altered and this candidate has not yet been exported to CAD or integrated into the lab XML.

`quincy_branch_search.py` creates the current fixed-dock 70-degree reach plan. Mobile-arc and short-segment scripts are experiments, not validated workflows. `quincy_oem_probe.py` tests the unmodified stock handle separately. `access_contact_probe.py` reports actual contact forces, alignment and finger linkage state.

Still to do: finish the nominal six-type positive regression, rerun missed-grasp/jam/constraint regressions, inspect rendered motion, provide an access viewer/video, document exact scope and any required adapter, and leave unrelated loaded-rack transfers guarded. Canopy and Nori height work from the earlier change are retained.

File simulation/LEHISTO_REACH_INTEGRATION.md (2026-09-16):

# Loaded-reach profile integration

`lehisto_loaded_reach.json` is consumed by special-stain placement and bath
targets. `lehisto_loaded_reach.py` provides per-rig FK shoulder/carriage frames,
radial and yaw screening, and fail-closed loaded-transfer admission. The tested
200–330 mm nominal bounds remain separate from the configurable 10 mm design
margin. Nori cannot use this profile. Collision, rack-bottom clearance,
payload, height, rail and grasp-frame evidence remain mandatory.

The actual standalone shoulder is z=0.027983 m, not the model origin z=0.
Thus its original jar-origin height relative to the shoulder is -0.092183 m.
The current lab row is -0.117143457 m: 24.960457 mm lower. This corrects the
initial audit's mistaken source-origin height. The source-to-lab rig rotation
uses the shoulder-based -90 degree mapping from `lab_row_test.py`; the actual
placed rig and rail transform is then applied, not a global hardcoded origin.

Five profile tests pass, including moved rig and carriage frames, margin versus
tested bounds, different payload/height/rail rejection, Nori rejection, and
required collision/clearance/grasp-frame evidence. `lehisto_lab_reach_audit.json`
and `lehisto_loaded_reach_audit.png` show the current placements. Active jars
4 and 5 are only 204.80 and 201.33 mm from the parked shoulder; spare jars 9–11
exceed 330 mm. The current row and its choreography were not relocated or
promoted to validated loaded motion by this integration.

The separate Physical Training task reported a successful proposed 30 mm
forward row shift for 4→5→6→7→8 using upright-rack dynamics, and is separately
working on all eleven baths. Its source and experiment files are untouched here.
Those experiments do not validate this lab's old tilted-tool choreography,
surrounding machinery, Nori interactions or all eleven original row positions.

The attempted cross-task report was blocked by the app's sharing approval
check. The findings remain available locally; no blocked message was bypassed.

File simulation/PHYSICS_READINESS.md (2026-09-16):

# ExHist: physical handling readiness

Status, 2026-09-14: **full-lab physical operation is blocked, not validated**.

## Equipment access update — 2026-09-15

See `ACCESS_VALIDATION.md` for source-matched nominal opening/closing tests of
the Quincy hinge, S60 slide door, ST5020 load/unload drawers, CV5030 load drawer
and TS5025 transfer drawer. These are actual-arm contact fixtures, with a fixed
chassis dock and provisional dynamics. Equipment has no actuator, grasp weld or
live pose setter. Missed grasps and excessive measured pull force stop progress.
The viewer is `launch.ps1 -Access <kind>`; the recorded-physics review is
`ExHist-Equipment-Access-Contact-Review.mp4`.

Quincy needs the separate proposed stand-off pull concept in this test; Leica
drawers use the v02 proposed U-pulls. Original machine CAD is untouched. The
printed green parallel slide/rack gripper is unchanged. This is not approval
to fabricate adapters or run hardware. Full-lab insertion and transfer guards
remain enabled. Historical findings below are superseded only for these
isolated access cycles.

`lehisto_loaded_reach.json` imports the independently tested nominal 200–330 mm
loaded radius, with a separate 10 mm design margin. Actual placed shoulder and
carriage transforms are used. `lehisto_lab_reach_audit.json` flags the different
lab height/tilt/rail trajectory; radial inclusion alone cannot admit a transfer.

## Equipment-facing operation and head cameras

The user approved explicitly provisional simulation parameters while keeping
hardware validation separate. `simulation_parameters.json` records that scope.
The new front-facing transfer mode replaces the test lift brake with a 150 N
force-limited lift servo (5,000 N/m stiffness, 200 Ns/m damping), retains CAD
travel limits and the middle-stage coupling, and leaves original CAD/source XML
unchanged. One collision pair between the nested lift's solid bounding proxies
is excluded; external lift collisions remain active. This is not validation of
the actual hollow telescoping geometry or its mechanism.

Run `arm_transfer.py --front` for the front-facing physical transfer and camera
report. Nori's chassis faces the table along its +X forward axis; the right arm
works in the front-right reachable area. The robot must be stopped and aligned
for 0.3 seconds before approaching. Heading departure over 3 degrees or tilt over
12 degrees faults the test. At the nominal 1 ms timestep, the sequence completes
with approximately 0.420 mm final placement error, 0.443 mm maximum relative slip,
over 99.9% bilateral contact and 2.915 Nm peak arm effort. Maximum heading error is
0.049 degrees; provisional lift effort peaks around 99.62 N, below its 150 N cap.

The initial half-timestep check exposed a 3.42 mm release shift, correctly failing
the placement tolerance. The front-mode provisional guide now has physical end
stops (25.6 x 1.4 mm clear slot, 20 mm tall), and release opens the jaws by 5 mm
per jaw over 1.5 seconds before retreating. No weld or relaxed tolerance was added.
Final error is 0.420 mm at 1 ms and 0.560 mm at 0.5 ms. These locating slots are
development fixtures, not a claim that existing equipment carriers have this design.

Three **fixed head-mounted** cameras are added to the new test and lab XML:
`nori_head_left`, `nori_head_right`, `nori_head_wide`. Their positions are anchored
to the imported head/visor geometry under `lift_top_link`, so base yaw and lift
travel carry the cameras physically. Their FOV and downward angles are provisional
simulation extrinsics, not calibrated real-camera parameters. They do not track
the slide or move independently to improve a result.

At sampled approach/grasp/lift/carry/release/retreat transitions, renderer
segmentation checks that at least one view contains the slide and both finger
meshes. The slide is visible in all three views at the tested transitions.
`head_camera_interactions.png` is the real rendered montage, and
`front_transfer_validation.json` contains pixel counts, contact and motion data.
These are sampled visibility checks, **not continuous occlusion guarantees or a
recorded training video**. Complete rack and drawer scenes still need their own
visibility checks.

`equipment_facing_docks.json` defines front-facing headings for all eight lab
stations. The current row requires +Y-facing chassis headings (90 degrees).
These are heading contracts; legacy dock stand-off and reach still need physical
validation. `equipment_dock_bench.py` separately drives and turns Nori through
wheel forces with the provisional lift servo, then admits interaction only after
the facing/stopped dwell check. It stops with about 1.39 degrees heading error.
No base pose commands occur after initialization.

`test_front_docking.py` adds seven groups covering facing/motion rejection, invalid
inputs, station headings, fixed head-frame motion, actual wheel docking, front-arm
transfer with camera evidence, and timestep comparison. All seven pass. The previous
25 baseline transfer/readiness groups were also rerun successfully. **The full-lab controller is still
in readiness hold**: physical loaded-rack transfers, LeHisto integration, drawer
handling and machine/container insertion have not been connected end-to-end.

## Actual-arm slide transfer milestone

`arm_transfer.py` now completes a development transfer using Nori's actual seven
arm joints: approach, two-jaw grasp, 40 mm lift, 100 mm horizontal carry, lower,
support confirmation, release and retreat. The slide is a free body. There are no
payload welds, mocap updates or payload pose assignments after initialization.
`pose_control.py` solves position AND orientation on scratch state, respects joint
limits, and leaves the live state untouched. Only actuator commands drive the arm.
Planning rejects sampled tabletop collisions; this is not a complete collision
audit of every imported robot surface.

At a 1 ms timestep the test achieves 39.73 mm peak lift, 0.767 mm maximum relative
slip, 99.853% bilateral-contact coverage and 0.461 mm final placement error.
The arm retains 4 Nm imported effort caps; the gripper cap is unchanged at 0.8 N.
Numerical friction refinement (`noslip_iterations=20`) prevents the creep seen
with the original solver settings. Gear equalities use a 2 ms solver time constant;
these are numerical contact/coupling settings, not changed physical fingers or
claims of real servo calibration. The original proven grooves remain unchanged.

`test_arm_transfer.py` passes eight groups, including successful 1 ms and 0.5 ms
rollouts, agreement of final placement, disabled-grip rejection, misaligned-slide
rejection, scratch-state isolation, passive payload structure and an open-jar probe.
All 17 prior readiness/mobile/gripper test groups also pass (25 groups total).
The full detailed rollout is in `arm_transfer_validation.json`; the four rollout
summaries are in `arm_transfer_regression.json`.

Important limits: this uses **development guide slots, not real rack slots**, an
explicit lift test brake, assumed base/caster parameters, and incomplete imported
robot contact proxies. It starts in a planned pre-grasp posture. It does not include
wheel travel while carrying, LeHisto sorting, loaded-rack retention, doors/drawers,
machine insertion or a glass-fracture model. A successful primitive is not successful
end-to-end lab processing. Main lab launch therefore remains readiness hold.

The matching 24-slide jar is now located and exported from **Slide Rack v13 /
Staining Jar**, not fabricated or substituted. Six genuine visual CAD jars are
restored to the special-stain table as passive free bodies in the operational XML.
Fusion face inspection establishes 98 x 44 mm inner flat dimensions, a -1.5 mm
inside floor and 91.8 mm rim in source coordinates, with 5 mm inner corner radii.
`cad_jar.py` preserves the open cavity using documented approximate contacts;
corner blocks and an un-beveled rim reduce clearance, and bottom blends are
simplified. Empty mass/inertia are provisional. Actual robot/rack insertion is not
yet tested. `export_rack24_jar.py` reproduces the export without editing source CAD.

The user has now approved explicitly provisional lift force, drawer resistance
and scanner-cassette dimensions for simulation-only integration. See the newer
equipment-facing section above. No unmeasured parameter is verified hardware;
scanner insertion and full-lab integration remain unfinished.

## Continued integration: physical mobility and guarded drawer tests

`mobile_base_bench.py` now runs the complete imported Nori on a free chassis with
wheel velocity actuators and `mj_step`. It drives 450 mm, turns approximately
90 degrees, drives another 350 mm and stops. No base pose is assigned after
initialization. Arm servos retain imported effort limits. The chassis is assumed
10 kg, wheel effort is provisionally capped at 1.5 Nm, and rear ball joints are
rolling-caster proxies. An explicitly named TEST FIXTURE brake holds the lift;
this is not a verified brake or a solution to the imported 1 N lift limit.
This standalone test does not validate navigation around lab obstacles or carrying.

Run `launch.ps1 -Mobility` for that live, wheel-driven development test. Default
launch still holds the full lab; `-Preview` remains animation-only. These are
separate modes, not a claim that the lab's old pose-driven controller is fixed.
`mobile_base_validation.json` records actual pose, stopped speeds, tilt, lateral
velocity and per-actuator peak efforts with units. `mobile_base_trace.json` records
wheel rotation and chassis motion. Disabled wheel motors do not navigate, and a
tilt fault remains latched after the pose recovers.

`drawer_contact_bench.py` uses the original left claw on an explicitly actuated
Cartesian test fixture, with a passive drawer slider. There is no drawer actuator,
weld, mocap or post-initialization pose assignment. It tests the original concept's
44 mm pull opening and a 64 mm test variant. **Neither completes the transfer**:
both trigger the 4 mm slip guard. A 30 N friction / 1 N actuator-cap negative case
triggers a force stop. Physics continues for 0.5 seconds after each stop to measure
residual drawer motion. Successful detection of these failures is not successful
drawer operation. Nominal 1.5 kg drawer mass, 2 N friction, 0.5 Nm grip cap, contact
friction and thresholds are assumptions, not machine measurements.

The left fingertips' approximately 55 mm distal bounding span flags the 44 mm
opening for an exact swept-geometry review, **not a proven clearance rejection**.
The bench uses conservative convex claw hulls and excludes coupled-finger self
contact; it cannot certify the real claw's contact surfaces. The wider test variant
also slips, so widening alone is not an established fix. Source CAD and the v01
pull exports are unchanged. The physically tested right/LeHisto grooves remain intact.

`test_mobile_drawer.py` contains six regressions: drive/turn/stop, disabled motors,
latched tilt fault, passive drawer structure, slip rejection and blocked-drawer
force rejection. Carrier retention, full six-dimensional arm alignment, exact
container interiors, supported insertion/release, machine latch/door forces and
full-lab controller integration **remain unfinished**. The matching 24-slide jar
has since been identified and restored as described in the newer milestone above.

## Correction after physical-build evidence

The prior flat-gap rejection and 1.03 kg hardware-weight inference were wrong for
this printed gripper. The user has physically printed and tested slide/rack pickup.
The image identifies the upper handle groove and lower slide groove. The earlier
"LeHisto Physical Training" task also records a successful lift-and-return
demonstration; its later 25-episode dataset concerns centered approaches, not a
general reliability certification. I reviewed that task's records, not the raw
training videos in this pass.

**Keep the original tested fingers.** No extra pads or replacement slide fingers
are required on the basis of the old flat-gap calculation. The original concave
grooves now use CAD-section convex partitions on Nori and all five LeHistos, with
separate oriented handle/slide grip frames. The legacy single convex jaw hull
filled these recesses. A regression probe verifies that the new groove stays open.

`groove_bench.py` is the current contact bench. The original lower groove lifts a
25 x 75 x 1 mm slide and the upper groove lifts a 20 x 2 x 7.5 mm handle-top-bar
coupon with a 9 mm neck, with no added pads, welds or payload pose commands. Both
hold for two seconds, with about **0.21 mm / 0.44 mm** relative motion. Misalignment
and near-zero closing force fail. This is a fixture/coupon test, not a loaded-rack
transfer or proof of hardware reliability. `contact_bench.py` and its pad results
are retained as **superseded historical experiments**, not the current design.

All 45 gripper bodies in Fusion had **Steel** assigned, including the printed
jaws, frame, camera bracket and electronic assemblies. The replacement
construction-based model is **0.2566 kg**, or **0.3332 kg** in a more conservative
material/tube/camera/cable scenario. It uses the manufacturer STS3215 mass of
55 +/- 1 g ([Feetech](https://www.feetechrc.com/products.html?keyword=STS3215)),
107.06 cm3 of printed parts at an assumed solid-PLA density of 1.24 g/cm3
([Polymaker](https://polymaker.com/wp-content/tech-docs/PolyLite_PLA_PIS_EN_V1.1.pdf)),
and two 125 mm aluminum tubes with 6 mm OD / assumed 4 mm ID. The
[Arducam B0332 datasheet](https://www.welectron.com/mediafiles/productimg/arducam/Amazon/B0332_OV9281_Global_Shutter_UVC_Camera_Datasheet.pdf)
does not give a net camera mass; 35 g nominal / 50 g conservative are allowances,
not sourced specifications. Filament, infill, tube ID and final wiring remain
unmeasured. This supports the user's sub-kilogram expectation, not a measured weight.

Mass and approximate inertia distribution are updated in the lab's Nori gripper.
The same exported-pose shoulder gravity term is now **2.81 Nm**, below the imported
4 Nm cap. That retires the previous 5.90 Nm warning for this pose; it does not
validate every loaded trajectory or the still-missing arm controller.

Eight proposed U-pulls (four per workstation) now follow the existing load,
unload, coverslipper-input and transfer-station drawer joints. They are passive,
with grasp/approach markers and no new drawer actuators. Four source-CAD-positioned
pull concepts, including 3.3 mm mounting bores, are exported separately as
`ExHist-Robot-Drawer-Pulls-v01.f3d` and `.step`; original machine CAD is untouched.
Fastening, real panel strength, latch forces, left-hand access and swept clearance
still need validation. `test_groove_updates.py` passes four additional test groups:
partition area, groove void, mass/frames/eight joint-following pulls, and bench results.

The old animation completed workflows by assigning joint coordinates and carrier
poses. It did not prove wheel motion, grasps, insertion or real equipment cycles.
The default launcher now opens a read-only readiness hold: robots, carriers and
passive doors do not animate and no batches are marked physically completed.
`launch.ps1 -Preview` explicitly enables the old **ANIMATION ONLY** view.

## Earlier readiness pass (pad experiment superseded above)

- A separate MuJoCo contact bench with the imported Nori/LeHisto jaw geometry,
  coupled jaw/pinion joints, force-limited fixture servos and a free glass slide.
  It uses `mj_step`, not payload position commands, mocap, attachment welds or
  adhesion. Its upstream lift is a test fixture, **not Nori's arm**.
- Pickup admission checks position and orientation. Lifting waits for 120 ms of
  two-jaw contact. Loss of contact or more than 2 mm relative slip stops further
  commanded lifting. A two-second hold must pass before a grasp is accepted.
- Both stock jaws and a **3 x 18 x 5 mm flat-pad concept** pass the nominal slide
  lift/hold test. Relative movement during the hold is approximately 1.10 mm and
  0.26 mm respectively. A misaligned slide is rejected; zero-friction contact slips
  and is rejected. Opening the jaws in the intentional drop test lets gravity move
  the glass. This is NOT a supported-placement demonstration.
- Reusable fail-closed checks cover six-dimensional alignment, two-jaw force,
  dwell, slip, joint/effort limits, container clearance, verified insertion paths,
  support contact and settling before release. Pose/grasp checks run in the bench;
  insertion/release checks are unit-tested but not integrated into a lab transfer.
- The three Quincy doors and two S60 doors now have passive CAD joints, exported
  pivots, axes and limits. The existing Leica joint imports are preserved. These
  new door joints have **no actuators or automatic motion commands**. Door masses,
  inertia and friction remain estimates and their contact geometry is not ready.
- Seven regression tests pass, including negative subcases, default no-motion
  hold, five passive door mappings, and the contact-only bench.

## Problems found in the actual assets

| Finding | Consequence / required change |
| --- | --- |
| Full lab: 257 joints, only one actuator, 20 mocap carrier variants | Joint-count coverage is not dynamics. Add physically driven robots, passive payloads and measured mechanical properties before enabling operation. |
| Distal flat gap is about 13 mm; handle neck is 9 mm | This comparison does NOT reject the actual upper-groove/top-bar grasp. Preserve the physically tested fingers and validate the correct grip surfaces. |
| All-steel CAD mass was 1.0305 kg | Superseded by the construction-based 0.2566 kg estimate; hardware weighing remains desirable. |
| Imported right shoulder-roll cap is 4 Nm; revised exported-pose gravity is about 2.81 Nm | This pose is below that cap with the corrected mass estimate. Dynamic loaded reach and actuator implementation still need validation. |
| Lift cap is 1 N; revised generalized gravity term is about 72.3 N | Importer/controller data remain incomplete. This is an unconstrained gravity term, not measured motor force or a complete transmission/mimic load calculation. |
| Glass is 25 x 75 x 1 mm; typical slide pitch is 3.535 mm, leaving 2.535 mm | Retain this geometry in the sim and test the demonstrated lower-groove extraction path. Do not infer a finger redesign from pitch alone. |
| 28 glass slides alone weigh about **131 g** at assumed density 2500 kg/m³ | Rack, handle, liquid and acceleration loads are additional. The low-force slide bench does not establish loaded-rack capacity. |
| Detachable handle is visually rigidly merged with the rack | The sim hides handle detachment. Model and test its retention separately; both jaws touching the handle does not prove the rack is secured. |
| Tool points used by the legacy IK are provisional; it solves position only | Calibrate the actual contact frame and approach axes. Solve full pose with limits, self-collision, scene collision and effort checks; fail if unreachable. |
| Base is moved using independent X/Y/yaw preview coordinates | It can slide sideways and turn independently of wheel travel. Replace with wheel-driven dynamics, odometry and body-heading control. CAD nominal wheel radius is 76.2 mm, track 300 mm. |
| Rear caster contacts are fixed spheres | They are not articulated rolling/swiveling casters; turning resistance and support geometry need an appropriate model. |
| Solid machine-envelope collision boxes and visual-only internals | They block real insertion and/or omit collisions. Build cavity, mouth, rail, stop and slot collision geometry from the correct CAD; preserve clearance under every joint pose. |
| Slides are merged into rack meshes; rack types change visually | Make slides independent passive bodies supported by actual rack slots. Coverslipping/scanning conversions must physically unload and reload them, never swap geometry to declare success. |
| Matching 24-slide buckets are absent; S60 cassette depth is provisional | Bucket and scanner insertion cannot pass yet. Use the actual matching CAD and measured clearances. |
| Leica source includes provisional joints and filling/reference slides | Those are not evidence of real powered mechanisms. Classify each joint as motorized, mechanically coupled, passive, fixed or reference-only before driving it. |

Measurements and source-derived model checks are reproducible in
`physics_readiness.json` and `audit_physics.py`.

## CAD changes to design next (not silently installed)

1. **Stainer drawer pulls for Nori's left hand.** Initial CAD/sim concepts are now added. Validate the pull and approach pose
   together, with finger clearance, mechanical attachment, full drawer travel and
   closed-door clearance. Model any latch separately. Validate pulling/pushing
   force, robot base stability and left-arm reach while the right hand carries a
   rack. A handle alone does not prove that a drawer can be opened.
2. **Secure rack transport interface.** Test the detachable handle under load.
   Consider a positively retained handle or a grasp around a structural rack rim.
   Preserve loading and coverslipper clearance. Do not obscure slides or sensors.
3. **Scanner/coverslipper carrier pickup features.** Their carriers need their own
   verified grip/approach frames or compatible removable handling adapters. Prove
   docking, insertion stops, capacity, clearance and adapter removal where needed.
4. **Preserve the existing lower slide grooves.** Reproduce the successful physical
   contact region and approach path, with force, clearance and contamination checks.
   The flat-pad idea is retired; do not redesign proven fingers to compensate for
   a collision-model error.
5. **Second Nori: defer.** Start with one Nori for rack/door work and LeHisto for
   individual slides. A second robot may help reach or throughput, but does not
   cure bad grips, incompatible carriers or missing mechanisms. Reassess after a
   single physical transfer and scheduling/collision analysis.

## Rule for passive objects and damage

Loose slides, racks, folders and containers get passive dynamics and support
contacts; they do not receive autonomous pose commands. Hinged/sliding doors and
drawers retain their real mechanical constraints and move only from applied
contact forces or a modeled real motor/linkage. A non-electronic item may of
course move when a powered conveyor or robot physically pushes it. A genuine
fixed/bolted fixture may remain fixed; a loose container must not be welded down
merely to make insertion pass.

The goal is **detect success or failure honestly**, not guarantee that a grasp
always succeeds. Missing evidence blocks the next action. A drop/slip/impact should
halt handling and flag the item for quarantine. No calibrated glass-fracture model
or experimentally supported break threshold is available; do not call an item
unbroken, or predict shattering, based on this bench.

MuJoCo contacts are soft constraints and ordinary mesh collision uses convex
representations. Accurate concave rack/bucket interiors need suitable decomposition
or primitive contact geometry. See the official
[computation documentation](https://mujoco.readthedocs.io/en/latest/computation/) and
[modeling guide](https://mujoco.readthedocs.io/en/latest/modeling.html).

## Verification and next milestone

Runtime: `C:/Users/Owner/Documents/Nori/.venv/Scripts/python.exe`.

Run `build_operational.py`, `groove_bench.py`, `test_groove_updates.py`,
`test_physics_readiness.py`, then `audit_physics.py`.
`contact_bench_validation.json` and `contact_*_trace.json` contain the measured
bench results; `contact_padded.png` shows the concept in contact with the slide.
Legacy workflow, robot-motion and machine-motion tests remain animation tests.

Before claiming an operational lab, implement and validate **one complete real
transfer**: choose the exact rack and matching container; verify handle retention;
calibrate both contact frames; solve a feasible joint trajectory; approach on
physical wheels; grasp under contact/effort limits; lift-test; carry; operate a
passive door if required; align and insert; verify support; release; withdraw.
Run missed-grasp, shifted-container, slip, obstruction, overload and loss-of-contact
cases. Only then extend that validated interaction to other stations.

Needed inputs: the matching 24-slide bucket CAD; verified Nori lift/arm/gripper
ratings and measured masses; and actual latch/drawer/carrier interface details.

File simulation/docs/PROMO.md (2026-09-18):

# ExHist Labs 60-second promo

## Current revision: v5

Looping latest promo

[Full-quality video](../promo_v5/ExHist-Labs-Promo-60s.mp4) ·
[Portable playback, run instructions and scoped evidence](../promo_v5/README.md)

The current film has the left parallel gripper/right stock claw, scanner slides
and supplied display image, background folder placement, upright rack transfer,
fading gripper close-ups, smooth camera, native stainer fork placement, and Nori
rolling away through the logo fade. It remains a staged simulation concept.

## Historical revision: v4

The remaining instructions and reports below describe the preserved v4 film,
not the current v5 motion or tool configuration.

[Play/download the video](../promo_v4/ExHist-Labs-Promo-60s.mp4)

Straight pickup from the taller concept oven

Upright carry before stainer insertion

The right parallel gripper is straight. Loaded trajectories retain an upright rack and reject large joint-configuration jumps. Left-claw oven closure, drawer access, restricted jaw release, stainer-fork pickup and rear-vessel placement are included. The concept ovens have 120 mm additional upper clearance, with unchanged shelf/pull heights. This is not native manufacturer CAD or an approved machine modification.

## Re-render the bundled motion

Modified oven geometry: [STL, millimetres](../cad/stl/quincy-promo-tall-concept.stl) and [static XML viewer, metres](../models/assets/quincy-promo-tall.xml). The original Quincy STEP in the main asset gallery remains the original-height model; no native STEP of this stretched concept is claimed.

After installing the root README's Windows exhist-sim environment (Python 3.10, MuJoCo 3.4.0):

```powershell
conda activate exhist-sim
python tools/unpack_assets.py
python promo_demo.py --render --sixty
python promo_video_verify.py
```

Output: promo_v4/ExHist-Labs-Promo-60s.mp4, 1280 x 720, 30 fps, exactly 60 seconds. Rendering needs desktop OpenGL. It replays bundled states and the exact background trace; no robot or camera connection is used. The pre-rendered video needs no Python environment.

The scene uses repository-relative resources. Motion, logo, manifests and a losslessly compressed background trace are included. Do not use the experimental --plan authoring option merely to watch the demo: it replaces motion and requires separate revalidation.

## Repeat scoped geometric checks

Use the separate Python 3.12 / MuJoCo 3.12.0 environment:

```powershell
conda activate exhist-access
python -m pip install -r requirements-promo-checks.txt
python tools/unpack_assets.py
python promo_solid_audit.py 1
python promo_postflight.py
```

The first check uses manifold3d for CAD-solid intersections across all 1,800 frames. The second checks orientation, grasp alignment, joint continuity/limits, container clearance, oven closure and rear-vessel seating. Rerunning replaces reports; keep a clean copy if preserving evidence matters.

Reports: [CAD audit](../promo_v4/promo_solid_audit_step1.json), [postflight](../promo_v4/promo_postflight.json), [decoded video](../promo_v4/promo_video_verification.json), [resource portability](promo-portability.json). Original reports remain in promo_v4/author-evidence and are not relabeled as fresh packaged tests.

## Limits

This is staged kinematic playback, not autonomous full-lab execution. Checks cover the oven/stainer interaction corridor, cross-arm geometry, rack/head/left-arm clearance and stainer motion against fixed equipment. Intended claw/handle and fork/rack contacts are excluded. Non-manifold robot meshes use conservative convex hulls; the reported solid-intersection threshold is 0.02 cubic millimetres. Frame sampling is not continuous-time certification.

Slides are fixed rack visuals here. Upright orientation does not validate retention under acceleration, vibration, slip or gripping forces. Full carrier exchange, coverslipper-to-scanner slide transfer, scanning, loaded folder handling and room-wide dynamics remain unfinished. The separately contact-tested LeHisto loop is described in the main README.

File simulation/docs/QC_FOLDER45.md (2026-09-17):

# QC folder cradle: final 45-degree layout

This is a **fixed concept fixture**, added only to selectable `exhist_rail_loop_qc45.xml`. Existing base XMLs and the eleven-bath validation evidence are preserved. No hardware is operated.

## Geometry and Coordinates

The pinned source is [LeHisto commit d6da8e0](https://github.com/histochemichael/LeHisto/tree/d6da8e09789b35e5a1595b4da6a9ddd3871c7cfe), not a live reference to changing experiments. See [the layout manifest](../qc_folder45_layout.json) for dependency hashes.

- Source tabletop z=-0.0697 m maps to lab tabletop z=0.800 m by translation [2.364, 0.700, 0.8697] m.
- Folder center [0.026, -0.240, 0.075] m maps to [2.390, 0.460, 0.9447] m.
- Tray is 45 degrees above horizontal; covers are held 100 degrees behind it. All 20 CAD pockets remain present.
- Ten stand solids: backing, lower stop, two stop links, two stop arms, two posts and two feet. Fasteners, materials, strength and flap clips still need engineering.
- Three source-holder boxes are included, centered at lab [2.604, 0.600, 0.8824] m, yaw 67.38 degrees. This is a fixture concept, not a manufactured holder design.
- CAD STL uses millimeters with the tabletop at z=0. Standalone XML uses meters at that same tabletop datum.

## Handling Provision

Two 80 x 340 x 150 mm side-access volumes are reserved. They are hidden bookkeeping sites, not robot grippers or obstacles. The existing Nori left arm is the proposed handler; a future two-arm Nori remains an option, not an added or tested robot. The cradle supports the folder during LeHisto placement in the concept, so Nori need not hold it continuously.

The folder is fixed in this layout. Nori reach, grasping, loaded exchange, passive retention and flap closing have **not** been validated. Lab LeHisto geometry remains at its original held pose; alignment of its robot frame and swept motion still need work.

## Checks

[Ten static layout checks](../qc_folder45_validation.json) pass: model compilation, unchanged robot degrees of freedom and dynamics, bench support, fixture footprint, cover clearance and conservative neighbor/access checks. The folder clears the tabletop by 15.7 mm. The nearest held LeHisto has a conservative bounding-box gap of 15.3 mm including the new source holder. This small static gap is not a certified moving-robot clearance.

Thirteen regression tests (five QC, eight existing loop tests) cover the layout and preserved model. The integrity check strips only named QC additions and requires the remainder to equal the base room model. New QC elements are fixed, non-contact context; they do not establish in-lab contact dynamics.

Separately, the source LeHisto simulation passed one upper pocket (zero-based row 4, column 1) at nominal and half timesteps, with open-gripper and 3 mm misalignment controls rejected. [Source video, CAD and evidence](https://github.com/histochemichael/LeHisto/blob/d6da8e09789b35e5a1595b4da6a9ddd3871c7cfe/docs/FOLDER45.md). Those results do not prove Nori handling, all 20 pockets, or full-lab slide-placement success. Rigid contacts omit glass fracture and cardboard compliance.

## View and Refresh

```powershell
python qc_folder_cradle.py
python lab_rail_loop.py --qc45
```

In the live lab viewer, select station 6 for QC. The optional composition retains the existing special-stain controller; this update does not rerun or replace its full eleven-transfer evidence.

`python qc_folder_cradle.py --build --render` regenerates the composition, standalone XML, stand STL, report and images from the pinned snapshot. The source builder in `source/qc-folder45` is provenance only, not a runnable lab experiment.

- [Whole QC station](images/qc-folder45.png)
- [Folder detail](images/qc-folder45-detail.png)
- [Matching stand STEP](../cad/step/Folder-Stand-45-Concept.step)
- [Stand Fusion archive](../cad/Folder-Stand-45-Concept.f3d)
- [Stand assembly STL](../cad/stl/Folder-Stand-45-Assembly.stl)
- [Standalone inspection XML](../models/assets/qc_folder45.xml)

This fixed QC fixture is included in the public ExHist simulation snapshot; it remains distinct from the staged Nori promo and the separately tested LeHisto pocket experiment.

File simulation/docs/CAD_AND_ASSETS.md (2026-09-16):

# CAD / asset provenance and units

## What is included

- Native STEP/STP assembly exports from the open Fusion designs: **LeHisto v38**, **Quincy 10GC - Bottom Shelf - Swing Door v1**, **Cardboard Slide Folder - 20 Place v1**, **Slide Rack v13**, **Leica Staining Rack v6**, and **Leica_ST5020_CV5030_Workstation_Mechanical_QC_v2 v2**.
- Existing STEP exports of the branded NanoZoomer S60, embedded cassette block, CV5030 30-position output magazine, drawer-pull v02 concept and Quincy pull concept.
- A component STEP export of **cassette_0 | Bottom cassette | DEPTH PROVISIONAL** from the open **NanoZoomer S60 v0** design.
- Exact simulation tessellations in JSON/OBJ, original robot STL meshes and their XML/URDF definitions.
- Consolidated STL exports of the twelve catalogued CAD-derived families, plus representative procedural room assets.

The handled Leica rack and scanner cassette exports include the current **unsaved in-memory Fusion state**. The export did not save, modify, replace or close the user's Fusion documents. Other exported named designs were unmodified at export time. A STEP file represents the assembly geometry at export, not a Fusion history/joint archive. The simulation's JSON tessellations are separate pinned inputs; do not assume a later CAD export proves every mesh version is identical.

## Units

| Files | Units / interpretation |
| --- | --- |
| `cad/step/*.stp`, `*.step` | Unit-aware native CAD exports; read the STEP unit definition. |
| `cad/stl/*.stl` | **Millimetres**, static triangulated visualization exports. |
| `models/assets/*.xml` | **Metres**, static inspection assets; furniture exported about a local center. |
| `assets/*.obj`, source tessellation JSON | Metres as used by the simulation. |
| Original robot STL meshes | Preserve original units; XML/URDF includes the corresponding scale. |

The standalone CAD gallery keeps native assembly coordinates except the S60/cassette axis conversion used for upright inspection. Thus it may not share the translated/rotated origin of a placed lab instance. Jointed, colored, collision-aware scene definitions remain in the main XMLs, not the flattened STL exports.

## Large assets

`leica-workstation.stp` is larger than GitHub's normal 100 MiB single-file limit. It and the large recorded traces are losslessly gzip-compressed in Git. Run:

```sh
python tools/unpack_assets.py
```

The decompressed hashes and sizes are in [compressed-assets.json](../compressed-assets.json). The unpacker refuses to overwrite modified files. You can also use a gzip-compatible archive utility. Git LFS is not required. See [GitHub's file-size documentation](https://docs.github.com/en/repositories/working-with-files/managing-large-files/about-large-files-on-github).

## Assets with no native STEP source

Nori's supplied package explicitly contains **no manufacturing CAD**: its STL meshes are simplified visualization models. We have not invented Nori STEP geometry or presented a mesh conversion as original CAD.

Benches, shelves, cabinets, chairs, PCs, architectural doors/windows, canopies, rails/markings, signs, glass-slide/coverslip primitives and support/collision fixtures are also represented procedurally or as simulation geometry. Their authoritative dimensions/transforms are in the Python builders and XMLs. Representative room assets have STL/XML exports and images; their lack of native STEP is explicit. The one-inch riser additionally includes an OpenSCAD source. Glass inside the validated rack loop is a fixed visual representation, not loose glass retention proof.

No new gripper, scanner adapter or manufacturing-ready design is implied by exporting existing assets.

## Validation boundary

The portable package rewrites only XML asset locations and author-specific source-model constants needed by supported launch paths. Source meshes, contact parameters, force limits, joint limits and controller logic are retained. The pinned reference manifest distinguishes author hashes from relocated XML hashes. See [distribution-provenance.json](distribution-provenance.json) and [portability-validation.json](portability-validation.json).

Older authoring/export/rebuild scripts and historical reports are retained for provenance. Some retain author-local paths, and are not supported clone-and-run entry points. They do not run during the documented launch sequence. An original report is not silently relabeled as a new test; the distribution's fresh loop run has its own current model hash.

Read [LICENSE-NOTICE.md](../LICENSE-NOTICE.md) before redistribution or reuse.

## Optional 45-degree QC folder cradle

The new pinned fixture includes ten component STLs plus an assembly STL in `cad/stl/Folder-Stand-45-*.stl`, a metre-scale standalone XML, and a separate whole-lab composition. It does not modify the previously validated base model. Native cradle STEP availability and the explicit handling/validation limits are documented in [QC_FOLDER45.md](QC_FOLDER45.md). The source experiment is evolving; only the local pinned geometry is used at runtime.

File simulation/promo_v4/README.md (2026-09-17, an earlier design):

# ExHist promo v4 — upright loaded-rack handling

The 60-second cut replaces v3's tilted tool pose and unconstrained loaded-arm transitions.

- Nori now uses the straight LeHisto-style grasp frame: zero intentional tool tilt.
- Loaded-arm moves follow Cartesian paths with an upright rack orientation constraint. Chassis yaw may rotate the rack horizontally, but may not pitch or roll it.
- Each simulated oven has 120 mm additional upper clearance. The shell, liner, upper door and hinge geometry are extended; shelf, controls and pull heights are unchanged. This is a modified concept envelope, not a claim about stock Quincy dimensions or a validated oven redesign.
- The previous single black oven pulls, oven closure, drawer handling, restricted jaw release, stainer pickup/rear-vessel placement and logo ending are retained.

Run from the parent directory:

```powershell
python promo_solid_audit.py 1
python promo_postflight.py
python promo_demo.py --render --sixty
python promo_video_verify.py
```

For this public package, follow [the portable demo guide](../docs/PROMO.md). Run tools/unpack_assets.py first. Rendering uses exhist-sim; geometric checks use the separate requirements-promo-checks.txt environment. Replanning is experimental, not the supported playback entry point.

Validation reports check all 1,800 video frames for rack tilt, groove alignment, container clearance, closure/placement and scoped CAD-solid intersections. The solid check covers the oven/stainer interaction corridor, including cross-arm and rack/head/left-arm checks. Intentional claw/handle and fork/rack contacts are excluded; non-manifold robot meshes use conservative convex hulls. Reported intersections exceed 0.02 cubic millimetres. Video verification binds the scene/state hashes to the decoded 60-second MP4.

This is staged kinematic playback. Upright orientation is not proof of slide retention under real acceleration, slip, vibration or gripping forces. Dynamic/hardware testing and continuous-time certification remain separate. Base lab assets and previous evidence are preserved.

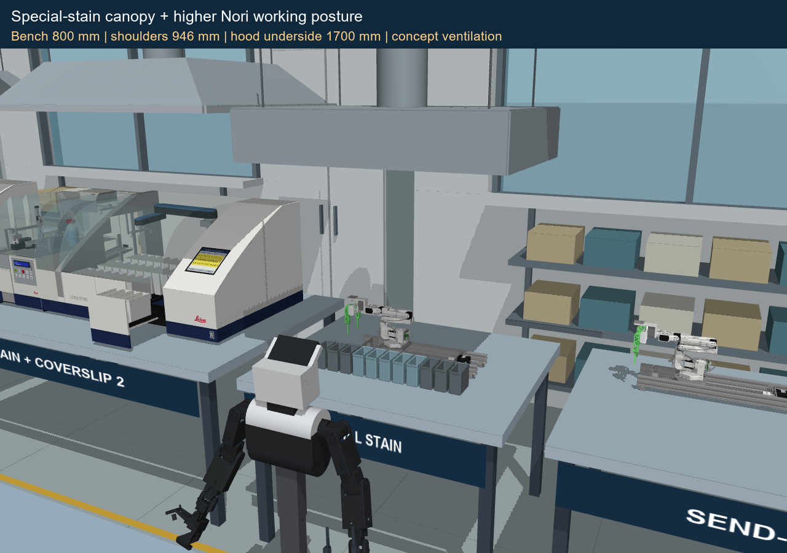
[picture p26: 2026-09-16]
simulation/special_canopy_nori_height.png

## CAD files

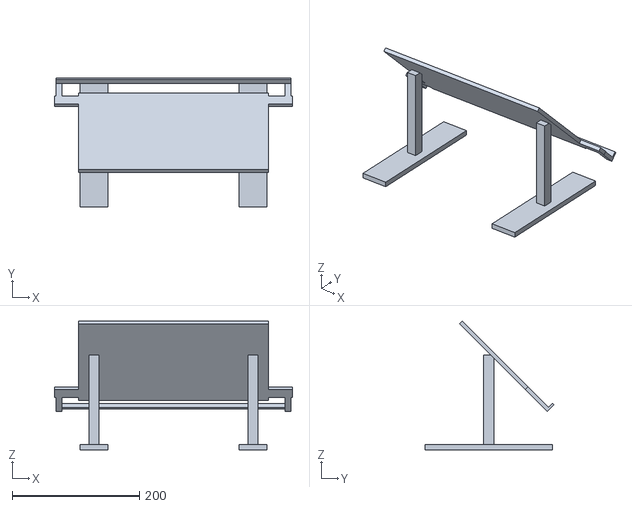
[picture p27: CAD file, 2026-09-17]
simulation/cad/stl/Folder-Stand-45-Assembly.stl
374.0 x 202.2 x 202.0

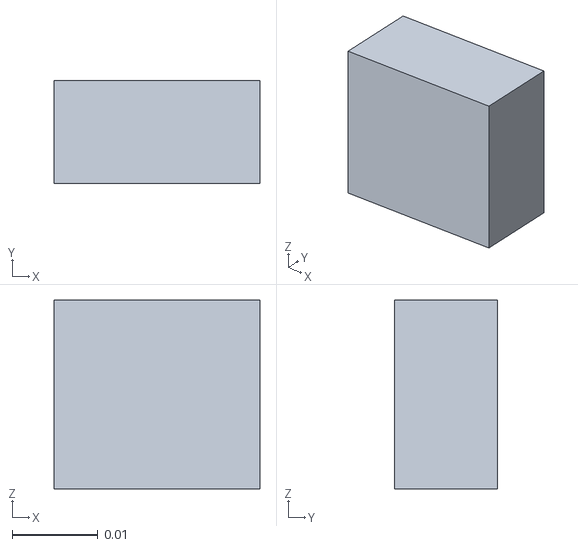
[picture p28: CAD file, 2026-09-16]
simulation/assets/art_leica_58.obj
0.024 x 0.012 x 0.022

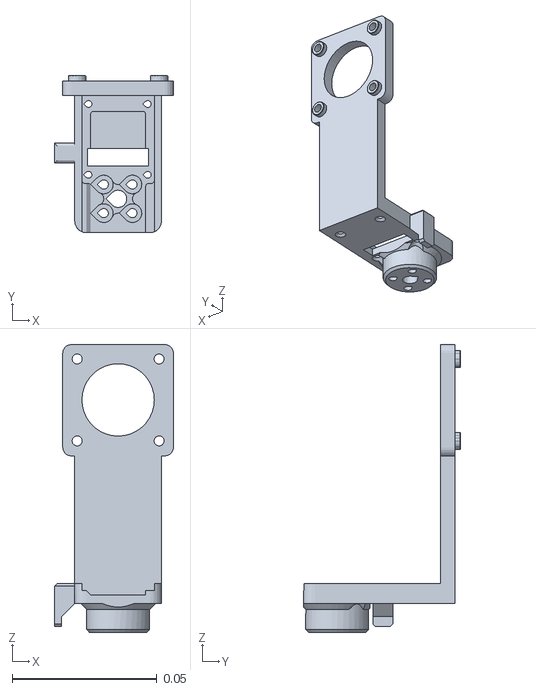
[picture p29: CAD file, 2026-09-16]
simulation/assets/nori/42_lehisto_part_20.stl
0.0411 x 0.0544 x 0.0995

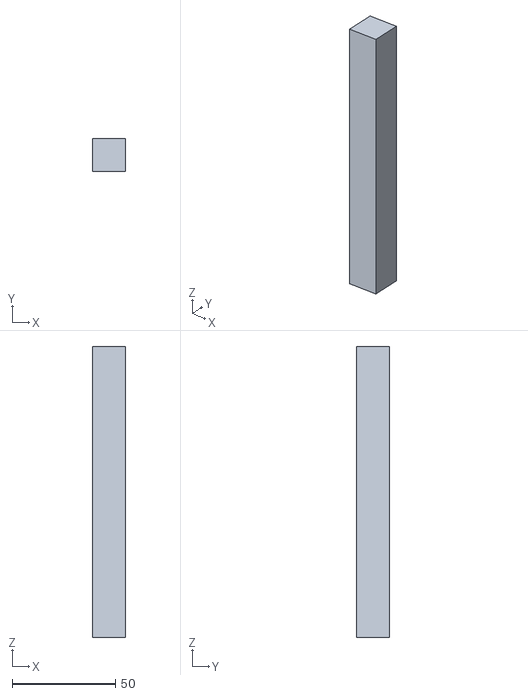
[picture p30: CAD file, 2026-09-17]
simulation/cad/stl/Folder-Stand-45-post_0.stl
16.0 x 16.0 x 140.9

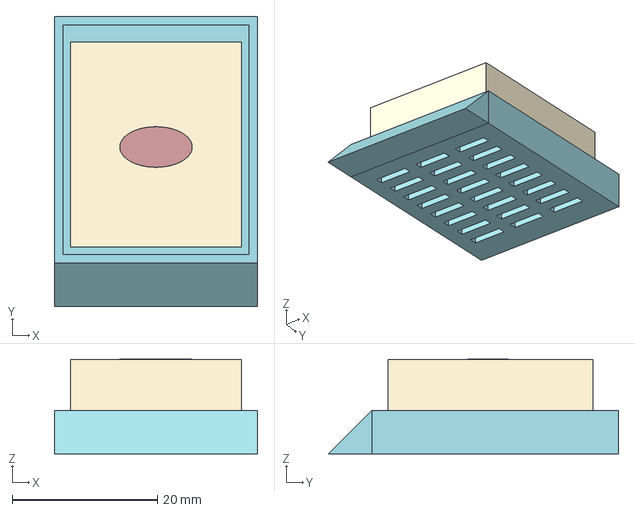
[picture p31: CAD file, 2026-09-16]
simulation/Histology-Embedded-Cassette-v01.step
28.0 x 40.0 x 13.1 mm

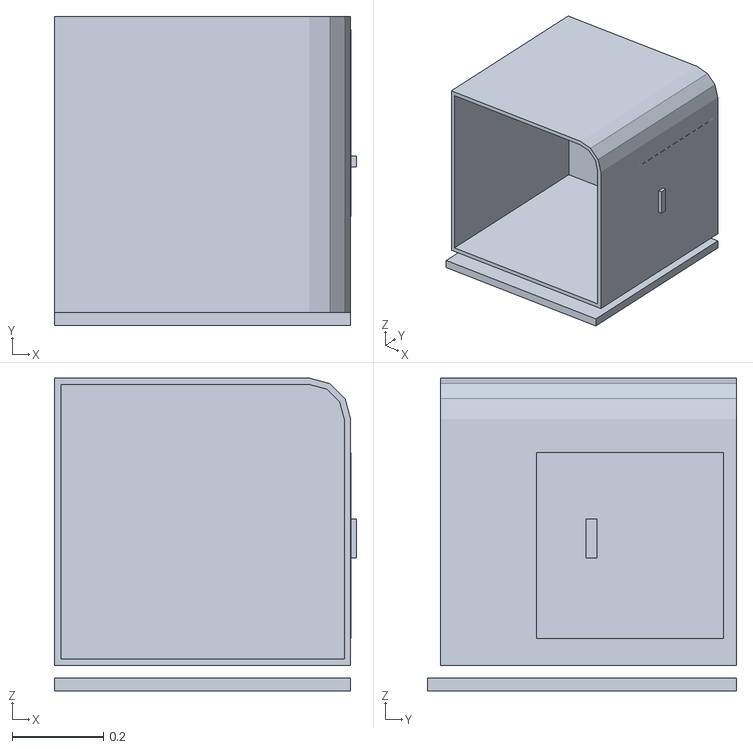
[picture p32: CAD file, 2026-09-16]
simulation/models/assets/meshes/s60_3.obj
0.663 x 0.678 x 0.686

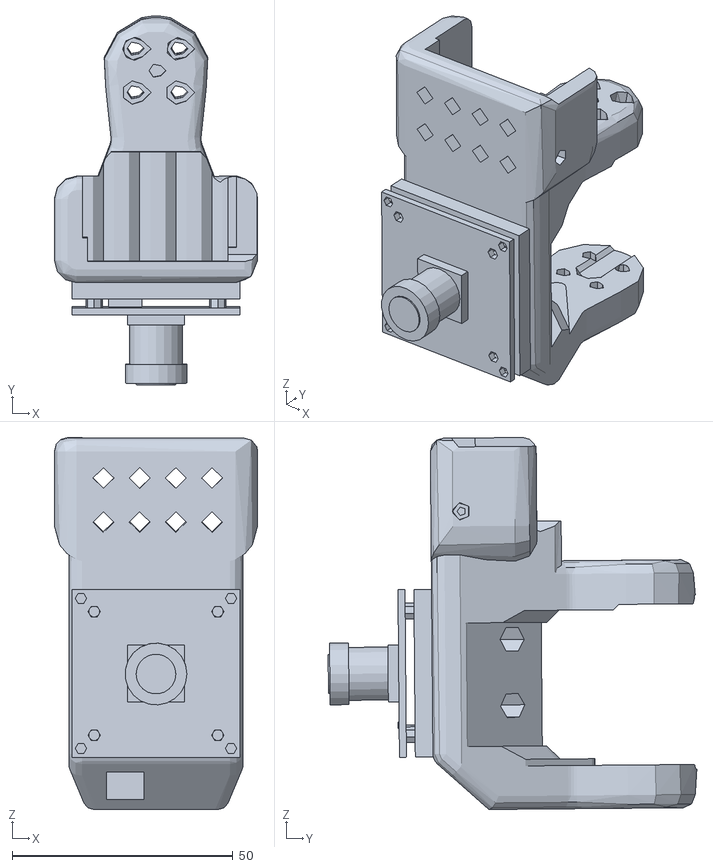
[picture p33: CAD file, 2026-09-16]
simulation/promo_v5/background-assets/campitch.stl
46.0 x 83.5 x 84.3

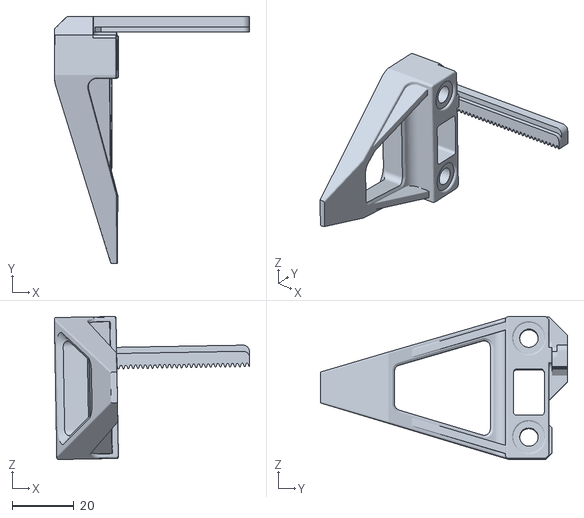
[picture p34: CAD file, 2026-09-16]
simulation/rail_loop_reference/source/robot/meshes/arm/clamp_2.stl
63.3 x 80.0 x 46.3

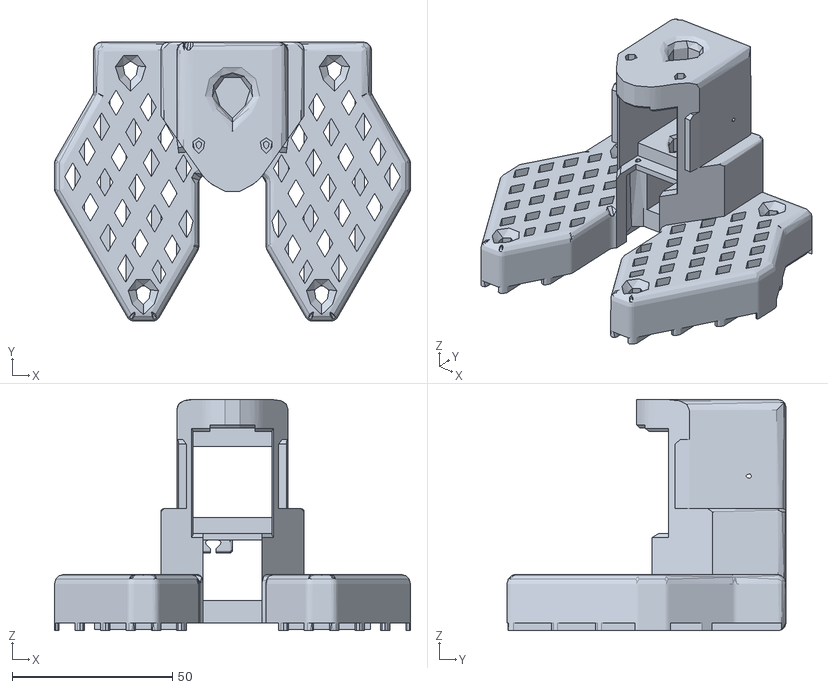
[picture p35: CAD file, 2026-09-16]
simulation/rail_loop_reference/source/robot/meshes/rig/armbase_ref.stl
110.9 x 87.0 x 72.0

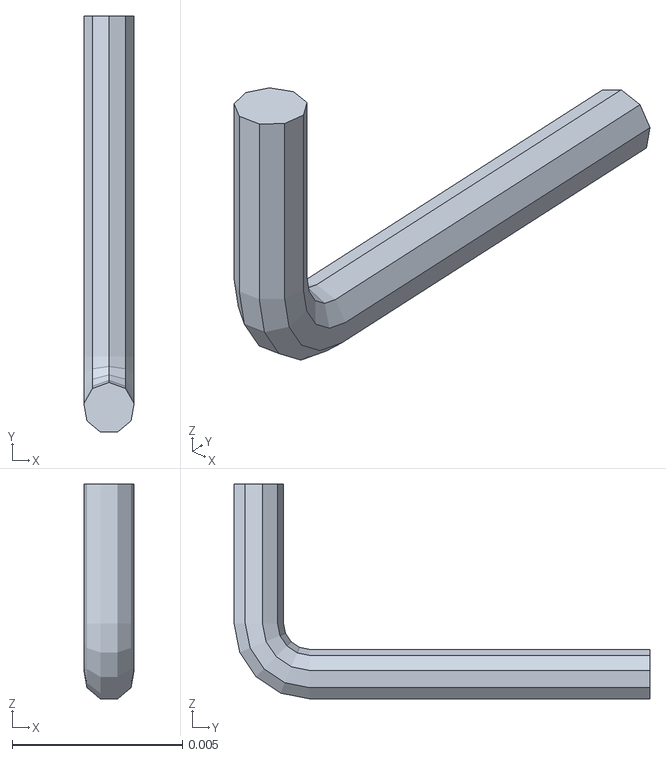
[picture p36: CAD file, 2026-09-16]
simulation/source/nori/lehisto_meshes/lehisto_part_08.stl
0.00148 x 0.0122 x 0.0063

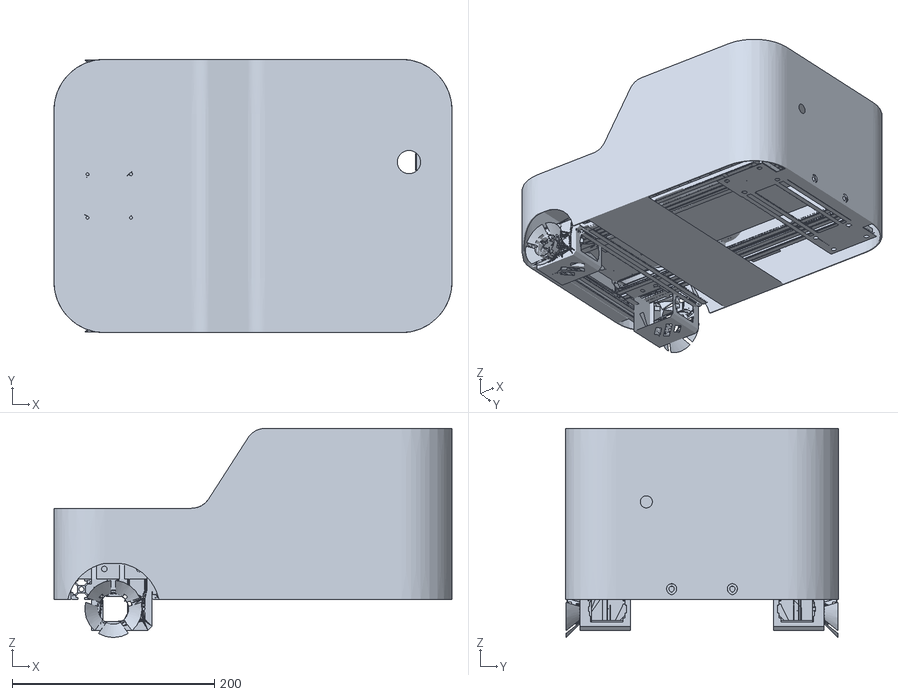
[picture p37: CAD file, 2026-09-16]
simulation/source/nori_description/meshes/visual/base_shell.stl
393.2 x 270.0 x 206.6

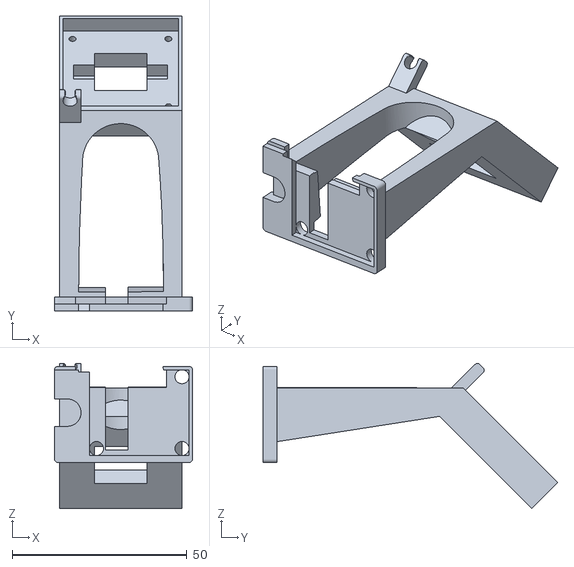
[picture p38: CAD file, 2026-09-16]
simulation/source/nori_description/meshes/visual/camera_mounts/right_camera_mount_mirrored.stl
39.4 x 84.2 x 41.5

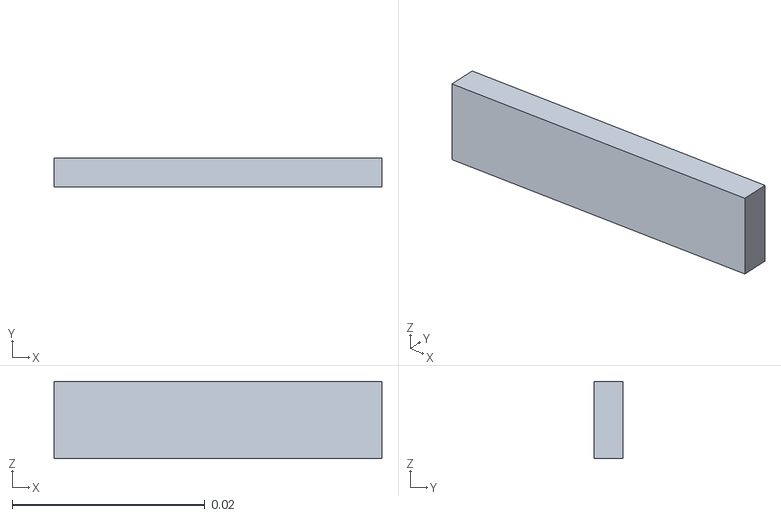
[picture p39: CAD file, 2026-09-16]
simulation/assets/art_leica_29.obj
0.034 x 0.003 x 0.008

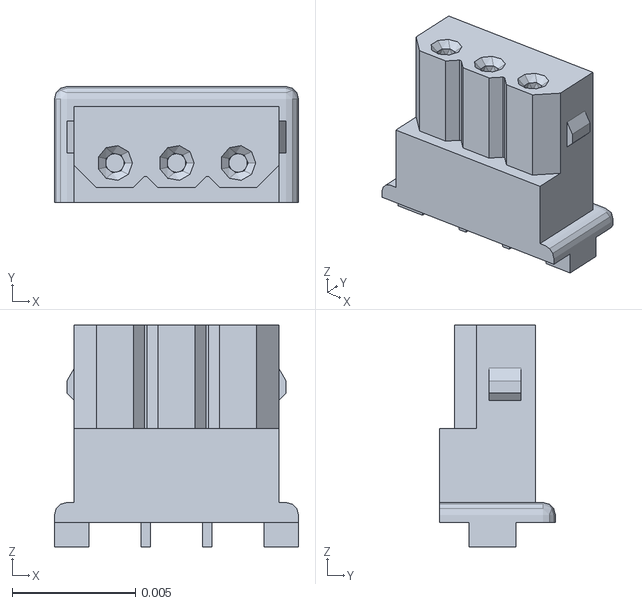
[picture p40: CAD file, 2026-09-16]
simulation/assets/nori/31_lehisto_part_09.stl
0.0099 x 0.0047 x 0.009

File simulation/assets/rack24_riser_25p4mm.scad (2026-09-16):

// Millimetres. Material/chemical compatibility not validated.
height_mm = 25.4;
linear_extrude(height=height_mm) polygon(points=[[-40.800000000000004, -20.0], [40.800000000000004, -20.0], [47.0, -13.799999999999999], [47.0, 13.799999999999999], [40.800000000000004, 20.0], [-40.800000000000004, 20.0], [-47.0, 13.799999999999999], [-47.0, -13.799999999999999]]);

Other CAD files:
simulation/cad/step/Folder-Stand-45-Concept.step
simulation/cad/stl/Folder-Stand-45-lower_stop.stl
simulation/models/assets/meshes/leica_workstation_handled_22.obj
simulation/ExHist-Quincy-Pull-Concept-v01.f3d
simulation/ExHist-Quincy-Pull-Concept-v01.step
simulation/ExHist-Robot-Drawer-Pulls-v01.f3d
simulation/ExHist-Robot-Drawer-Pulls-v01.step
simulation/ExHist-Robot-Drawer-Pulls-v02.f3d
simulation/ExHist-Robot-Drawer-Pulls-v02.step
simulation/Histology-Embedded-Cassette-v01.f3d
simulation/NanoZoomer-S60-branding-v05.f3d
simulation/NanoZoomer-S60-branding-v05.step
simulation/S60-before-branding.f3d
simulation/assets/art_lehisto_0.obj
simulation/assets/art_lehisto_1.obj
simulation/assets/art_lehisto_10.obj
simulation/assets/art_lehisto_11.obj
simulation/assets/art_lehisto_12.obj
simulation/assets/art_lehisto_13.obj
simulation/assets/art_lehisto_14.obj
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

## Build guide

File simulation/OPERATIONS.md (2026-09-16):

# ExHist operational workflow demo

**Current default: PHYSICS READINESS HOLD.** Run launch.ps1 for stationary inspection. Full physical operation is blocked pending contact, actuator, carrier and clearance work. See PHYSICS_READINESS.md for the current audit and separate contact bench.

The remainder of this document describes the **legacy kinematic animation only**. Run `launch.ps1 -Preview` (or `operate_lab.py --preview`) to opt in. It starts at 2x demonstration speed; its completion counts are not physical successes.

Controls: Space pauses; R resets the batch run; F fails the next completed scan; C recovers faulted stations and retries the scan; 1–8 focuses a table; O shows the entire lab; T follows Nori; + / - changes speed.

Four batches (36 uniquely tracked slides) follow sorting, baking, routine or special staining, coverslipping, curing, QC, scanning and packaging. Equipment slots are reserved before transport; a single Nori transport queue retains batch custody during transfers. Coverslipping and curing stay on the same routine workstation. Carrier changes preserve slide IDs. The QC step here is a slide-processing workflow placeholder, not automated block-image assessment.

The normal and injected-scanner-fault tests both complete 36 slides with 21 paired pickup/dropoff events. The MuJoCo model also compiles and completes a 3,390-frame kinematic check. See workflow_validation.json and operational_validation.json. Live runs save their events and slide records to workflow_live.json on completion or viewer close.

## Stainer and coverslipper articulation

Both Leica workstation copies include all 84 source CAD joints: 10 rigid relationships and 74 moving joint assemblies per copy. Seven planar joints each expand into three coordinates, including a locked rotation, giving 88 imported coordinates per workstation. CAD poses, axes and limits are retained in assets/leica_kinematics.json; the complete source-to-simulation map is in machine_articulation.json. Hidden optional/reference joints remain present without reintroducing their hidden visual proxies.

Staining drives ST5020 motion trials; coverslipping drives CV5030 motion trials. Independent machine labels and activity lights indicate RUNNING, IDLE, CURING, PAUSED or FAULT based on the simulation scheduler—not equipment telemetry. Doors, hoods, drawers, filling references and transfer-reference joints are available for inspection but do not all cycle automatically. Small periodic strokes are illustrative, not manufacturer operating sequences.

Press X for transparent-enclosure inspection. Press J to pause and enter the joint inspector; [ and ] select a coordinate, G makes a small jog, and H restores its exported pose. Space leaves inspection and resumes the workflow. Locked coordinates are identified and do not move.

test_machine_motion.py checks all 162 unlocked imported coordinates across both copies, 14 locked coordinates, source coverage, joint limits, pause/fault freeze and completion of the 36-slide workflow. It does not validate internal collisions, rack insertion, coverglass transfer, processing quality or real hardware. Placeholder inertias are unsuitable for dynamic verification.

## Boundaries

The lab now includes a provisional 18.4 x 8.9 m furnished room, shown as a three-sided cutaway: four observation windows, two closed doors, four tall storage cabinets plus under-bench drawers, five shelving bays, four additional work tables and task chairs, and two additional PCs. Processing-zone signs, lights and floor markings identify the bays. New furnishings remain outside the Nori aisle; test_room.py checks the complete workflow against their collision geometry. O opens the full-room overview; 1–8 still focus the equipment stations. Furniture is static, and this is not an ergonomic or building-code validation.

Two conceptual suspended canopy hoods sit over the ST5020 stainers, with tapered housings, 200 mm duct stubs and hanger rods to a provisional 3 m ceiling datum. Each is approximately 1.36 x 1.05 m with its lowest lip at 1.88 m, 0.49 m above the static CAD machine envelope. These are geometric placeholders, not engineered ventilation or structural designs; capture performance and all-pose clearance remain unvalidated. canopy_hoods.py preserves them during scene rebuilds.

This is a workflow simulation with robot-motion trials, NOT an operational physical lab or a validated robotics controller. Equipment processing is logical; physical rack insertion, individual-slide loading and grasp/contact physics are not implemented. Carriers still move independently through visual handoff poses, not solved robot grasps. Cycle times, travel speed and table dimensions are demonstration assumptions, not throughput or safety validation. Scanner cassette and output-magazine conversions are logical, and scanner carrier capacity compatibility still needs validation.

## Articulated robots

Leica racks use the corrected detachable handle exported from the live Leica Staining Rack v6 CAD: 100.51 mm handle top, copied 24-slide-rack grip, 28 slide positions loaded with 15–16 reserved for the handle. The shared carrier asset and eight rack locations inside each Leica workstation include it; empty embedded racks remain empty. Original source JSON exports are retained. Handle retention, detachment forces and coverslipper compatibility remain unvalidated. See handled_rack_validation.json for geometric alignment checks.

All five LeHistos use source Fusion v38 as-built joints and rigid groups: 532 CAD parts each, with no fallback part assignments. Ten joints per mechanism cover the carriage, lead screw, five arm joints, two jaws and pinion. They execute local position-IK motion trials during assigned station work and hold when idle or paused. These are not yet rack pick/place trajectories. Slide coordinates are converted from CAD centimeters to meters; revolute limits remain radians.

Nori is sourced from the saved "Nori with parallel histo gripper.xml" model. The right wrist has the parallel histology gripper; the original left gripper is retained. Nori executes a right-arm carry/reach trajectory and an approach/retreat at handoff phases. The provisional docking offset is 0.95 m from the aisle pose. Both parallel jaws translate together with the source rack/pinion coupling and actuator target preserved. The left arm remains at its imported pose. Position-only IK reaches the trial target within 1 mm, but tool orientation and grasp contact have not been solved. The tool point is provisional in the parallel-gripper mounting frame.

test_robot_motion.py verifies all five LeHistos and Nori move, joint limits remain respected, all 36 slides finish logically, and no greater-than-1-mm table/machine penetration is detected through the sampled workflow using Nori's existing coarse colliders. It does NOT validate self-collision, continuous-time clearance, rack contacts or LeHisto collision geometry. Results are in robot_motion_validation.json; source mappings are in articulation.json.

Special-stain buckets are not fabricated stand-ins in this viewer: six purple targets mark the pending matching 24-slide-rack bucket CAD. The previous static layout remains separately accessible through run_lab.py and still contains its older bucket placeholders. The generic embedded cassette CAD is nominal and needs comparison to the actual cassette used.

## Rebuild and tests

Use C:/Users/Owner/Documents/Nori/.venv/Scripts/python.exe:

1. build_scene.py
2. build_operational.py
3. test_workflow.py
4. operate_lab.py --check-render
5. operate_lab.py

Next implementation layer: align actual rack handles with calibrated tool frames, add LeHisto and rack contact geometry, enforce orientation and self-collision constraints, couple payload custody to successful physical grasps, and validate instrument loading. Hardware adapters require explicit interlocks. Do not connect this demo directly to real equipment.

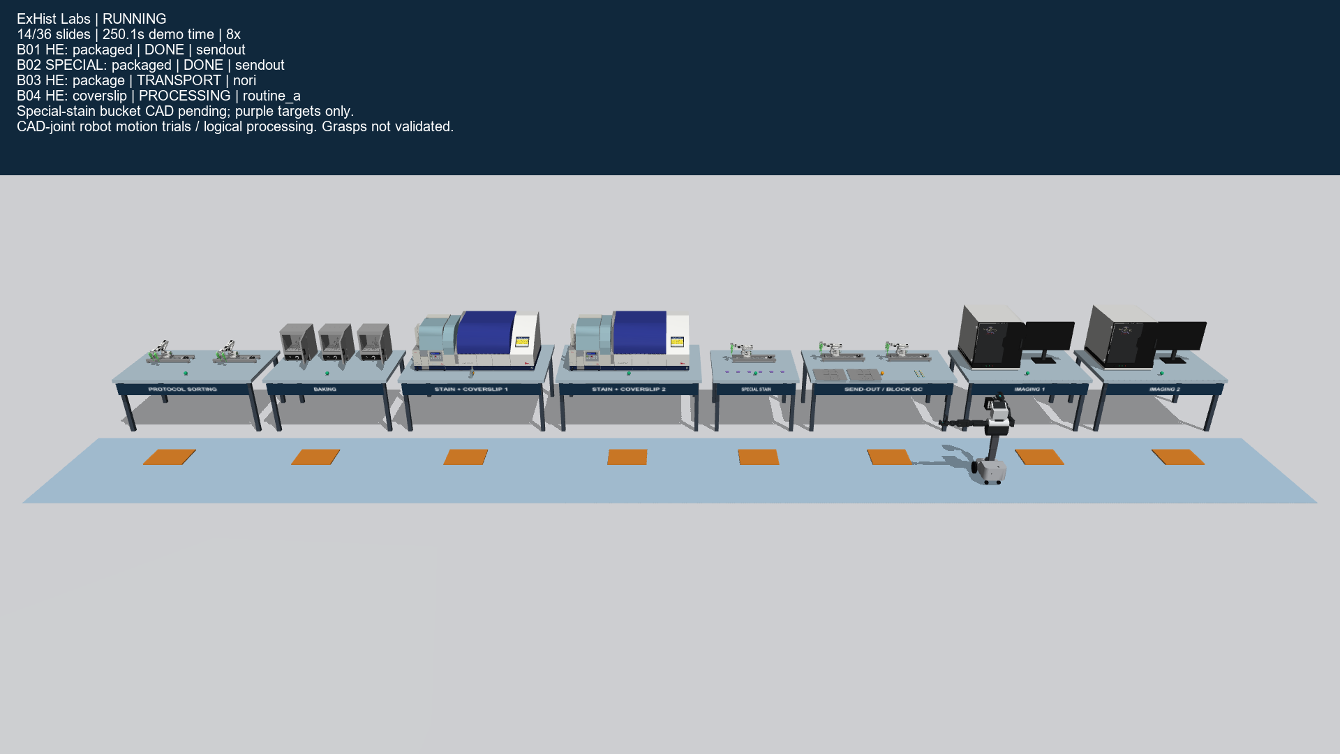
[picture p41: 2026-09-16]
simulation/operational_2500.png

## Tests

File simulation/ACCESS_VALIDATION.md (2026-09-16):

# Equipment access — nominal contact validation

Historical recording: the controller was subsequently updated for latched grip stance and live terminal holding. See STABILITY_VALIDATION.md and the source-matched stability reports for the current controller. The video and measurements below retain their original provenance.

Six isolated, fixed-dock MuJoCo cycles. Nori uses its actual seven-joint left arm, stock left claw and force-limited lift. Each equipment joint is passive. These are simulation results, not hardware certification or full-lab transfer readiness.

| Mechanism | Maximum opening | Closed residual | Peak arm torque | Relative grip slip | Bilateral contact |
| --- | ---: | ---: | ---: | ---: | ---: |
| quincy | 70.197 deg | 0.0000 deg | 3.055 Nm | 1.532 mm | 99.986% |
| s60 | 199.833 mm | 0.4451 mm | 2.667 Nm | 0.141 mm | 99.999% |
| st_load | 179.007 mm | 0.0000 mm | 2.477 Nm | 1.286 mm | 99.992% |
| st_unload | 179.099 mm | 0.0000 mm | 2.361 Nm | 1.334 mm | 99.992% |
| cv_load | 179.116 mm | 0.0000 mm | 2.377 Nm | 1.345 mm | 99.992% |
| ts_drawer | 179.107 mm | 0.0000 mm | 2.238 Nm | 1.244 mm | 99.997% |

## Safeguards and reproduction

- 0.25 ms physics step. Original 4 Nm arm caps; 1.5 Nm claw cap; provisional 150 N lift cap and 3 N commanded assist.
- Actual measured handle pull above 12 N for 30 ms stops motion. This is a sustained-force stop, not a guarantee that brief peaks remain below 12 N.
- Deliberately jammed ST load drawer stops with 1.534 mm maximum travel; missed-grasp regression never enters OPEN.
- Joint limits, finger mimic, bilateral contact, slip, collision, timeout and force checks stay active. No live equipment pose assignment, actuator, weld or mocap attachment.
- Only nested telescopic proxy overlaps and proximal claw-gear/socket overlaps are internally exempted. Distal fingers and external equipment contacts remain active.
- Quincy uses the separate proposed 35 mm stand-off / 10 mm round pull; Leica drawers use the v02 U-pulls. Scanner uses its existing CAD handle. Original machine and printed slide/rack-gripper designs are unchanged.
- CAD concepts: ExHist-Quincy-Pull-Concept-v01.step/.f3d and ExHist-Robot-Drawer-Pulls-v02.step/.f3d. Mounting, materials, latch forces, thermal/load suitability and manufacturing approval remain open.
- `python access_suite.py` reproduces the positive cycles and physics-state recordings. `python -m unittest test_equipment_access -v` checks passivity and failure handling. `python verify_access_artifacts.py` rejects stale results.
- `launch.ps1 -Access quincy` opens the real-time fixture. Other kinds: s60, st_load, st_unload, cv_load, ts_drawer.
- Video: ExHist-Equipment-Access-Contact-Review.mp4 is a 3x replay of recorded dynamic states. The fixed head-side inset is a proposed camera bracket, not a calibrated hardware mount; external views complement any arm occlusion.

## Remaining scope

The chassis is fixed at each dock. The fixture checks the arm, selected door/drawer panels, handle and bench; it is not exhaustive cabinet/interior collision validation. No mobile approach, rack insertion/extraction or full-lab production readiness is claimed. The main workflow remains guarded. The special-stain canopy and 800 mm tables / higher Nori work posture are retained.

## Provenance

Controller, collision geometry, hinge interface and all six reach plans share the source hashes stored in access_final_validation.json. The source-hashed recordings are access_<kind>_states.npz; each report retains events and force traces.

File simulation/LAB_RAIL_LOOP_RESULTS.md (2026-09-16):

# LeHisto moving-rail loop in ExHist Labs

PASS: a fresh 313.249-second contact-driven run completed all eleven loaded
transfers, 1 → 2 → … → 11 → 1, with the original gripper and 25.4 mm inserts.
The rack was released and supported at every destination. The full-room view
preserves the current Leica glazing, canopy, furniture and raised Nori posture.

## Measured results

- Carriage: −60.0002 to +210.0011 mm; returns to its starting end.
- Peak rail speed: 19.63 mm/s, below the original 100 mm/s limit.
- Minimum rack clearance over rail: 50.97 mm; over container rims: 41.07 mm.
- Maximum relative grasp slip: 1.473 mm.
- Maximum seated lateral error: 0.526 mm.
- Rack/rail contact: zero. Joint-limit violations: none.
- Original 145 g loaded-rack model, ±1.5 Nm arm caps, joint limits and contact
  guards retained. No payload weld, hop reset or runtime rack-pose controller.
- The actual bounded tabletop replaces the isolated test's infinite support
  plane. The negative control confirms an off-table rack falls to the room floor.

The route completed and its trace was saved before a NumPy-boolean JSON export
error. That exporter is fixed. The report was recovered against the unchanged
model hash. The additional two-second released-rack hold was rerun from the
measured final state; it was stable. This recovery is recorded explicitly in
`rail_loop_lab_validation.json`, not described as a second full route run.

## Run and inspect

- `launch.ps1` or `launch.ps1 -LeHistoLoop`: complete lab, paused at startup.
- SPACE: start/pause. L: LeHisto detail. O: whole room. 1–8: stations.
- `launch.ps1 -Hold`: previous readiness-hold viewer. Access/mobility tools remain.
- `ExHist-Live-LeHisto-Rail-Loop.mp4`: 80.33-second review at 4× speed, including
  the actual gripper-camera view and whole-room overview.
- `lab_rail_loop.py --validate`, using the existing lerobot Python environment:
  rerun the live controller; `test_lab_rail_loop.py`: integration/evidence guards.

## Scope

This is the live LeHisto contact station within the full lab scene, **not a fully
coupled operational lab**. Other robots/equipment are held visual context.
Nori handoffs, neighbor-machine/person collisions, loose-slide loading, fluids
and hardware operation are not validated by this loop. The loaded-rack model
uses fixed slide visuals; it is not proof of individually retained loose slides.

The rail uses the existing 270 mm modeled stroke, not the full 600 mm extrusion.
The far-side crossover goes above the rail; this is not a 360-degree orbit around
both physical ends. The source experiment and older first-pass video remain
unchanged. Both current CAD/layout inspectors use the new eleven-bath placement.

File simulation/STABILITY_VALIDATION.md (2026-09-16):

# Grip stance and passive-object stability

PASS in the tested simulation fixtures. No passive-body freezing, added payload welds, pose resets or hidden motion are used to obtain stability. Full-lab transfers and hardware reliability are not certified.

## Controller changes

- Retain arm/lift motor targets throughout settle, grip, hold and release. Replan only explicit approach, opening, closing and retreat motions.
- Preserve loaded motor targets on stop/completion; do not replace them with the contact-deflected measured joint pose.
- Require both fingers to clear the handle for 100 ms before retreat. Opening jaws alone is insufficient.
- Keep physics stepping in the access viewer after completion instead of displaying a frozen terminal frame.

## Live tests

Each equipment cycle includes 8 s untouched idle, 5 s loaded hold and 10 s post-retreat live holding. Poses are sampled at 500 Hz; physics runs at 4 kHz. Quiet-window measurements exclude the first second of ordinary contact settling. Full acquisition/release tip excursion is also checked separately (<1 mm).

| Mechanism | Loaded-hold tip span | Acquisition tip span | Quiet orientation excursion |
| --- | ---: | ---: | ---: |
| quincy | 0.169 mm | 0.209 mm | 0.0272 deg |
| s60 | 0.125 mm | 0.190 mm | 0.0173 deg |
| st_load | 0.062 mm | 0.160 mm | 0.0078 deg |
| st_unload | 0.062 mm | 0.160 mm | 0.0085 deg |
| cv_load | 0.062 mm | 0.160 mm | 0.0086 deg |
| ts_drawer | 0.062 mm | 0.160 mm | 0.0086 deg |

All six stationary motor targets remain unchanged. Untouched equipment travel is zero. The 31 free passive bodies pass a 30 s gravity/contact soak; worst position span after 2 s settling is 0.00107 mm.

25 regression tests pass, including missed grasp, jam stop, latched stance, exact bath transform and a negative control where removing the table makes the rack fall.

## Layout and limitations

- Active exhist_operational.xml uses the currently selected eleven-bath layout and matching insert orientations supplied by LeHisto Physical Training. The newer moving-rail integration has separate evidence in rail_loop_lab_validation.json; previous parked-carriage routes remain preserved. The original tilted five-bath film is historical, separate choreography—not new physics proof.
- The passive soak covers 11 containers, 11 one-inch inserts, one loaded-rack support envelope and eight QC blocks. QC mass (20 g) and support-only envelopes are provisional.
- Doors/drawers use fixed-dock Nori tests, provisional dynamics and proposed adapters where documented. Whole-cabinet, mobile approach and neighbor-machine collisions are not exhaustively certified.
- Loose slides, loaded slide folders, scanner/coverslipper carrier exchanges and coordinated Nori/LeHisto handoffs remain unvalidated. The live rail-loop station uses a separate composed lab scene with other equipment held as visual context. Existing full-workflow guards stay enabled.
- The earlier equipment-access video/reports predate this controller update and are historical. Current stability evidence is in stability_<kind>_current.json/.npz and stability_validation.json.

## Reproduce

`python stability_audit.py --kind quincy` (repeat for s60, st_load, st_unload, cv_load, ts_drawer); `python passive_stability.py`; `python -m unittest test_stability test_equipment_access test_lehisto_loaded_reach test_first_pass test_jar_riser test_review_corrections -v`; `python verify_stability.py`.

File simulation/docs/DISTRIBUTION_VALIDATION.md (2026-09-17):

# GitHub distribution validation — 2026-09-15

The distribution is a separate copy; it does not replace the author's working lab.

## Public snapshot update — 2026-09-17 UTC

The current package adds the upright-rack 60-second promo and final pinned QC fixture assets. Fresh checks on this copy passed: all three base models compiled and the live controller initialized; all 13 existing loop/QC regressions passed; the promo's 1,800-frame CAD-solid audit reported zero unintended intersections in scope; postflight confirmed maximum rack tilt 0.0174 degrees, minimum container clearance 0.612 mm, closed oven and correct rear-vessel seating. The full 60-second MP4 was re-rendered here, decoded to 1,800 frames and checked against its source hashes and ending logo. This does not add a full-lab physical success claim.

All 430 promo resources match the author's bytes, and only XML resource paths were relocated. Original reports are retained separately under promo_v4/author-evidence. [Current promo guide](PROMO.md) and [portability record](promo-portability.json).

The final 45-degree QC concept now includes matching native Fusion/STEP alongside STL/XML; earlier snapshot notes below are historical. The taller promo oven has STL/XML only, explicitly distinct from the original Quincy STEP. Common token/private-key patterns, oversized Git files and documentation links were checked without printing candidate secrets; see [publication check](publication-check.json).

## Optional QC layout addition — 2026-09-16

The selectable `exhist_rail_loop_qc45.xml` adds a pinned, fixed 45-degree folder cradle. The base model and evidence below remain byte-for-byte unchanged. Five additional QC tests and all eight existing loop tests pass. The optional composition compiled and initialized the live special-stain controller for 0.080 s; its eleven-transfer route was not rerun. See [QC_FOLDER45.md](QC_FOLDER45.md) for static clearances, source-candidate status, and explicitly unvalidated Nori/slide-placement handling. The new cradle's STL/XML do not imply a matching finalized native STEP yet.

## Fresh packaged contact route

A fresh live run using Python 3.10 / MuJoCo 3.4.0 / PlaCo 0.9.20 completed **11/11** transfers in 313.249 simulated seconds, then kept physics running for a continuous two-second released-rack hold.

- Minimum clearance above the rail: **50.974 mm**.
- Minimum transfer/rim clearance: **41.068 mm**.
- Maximum relative grasp slip: **1.485 mm**.
- Rail contact: **0 N**; joint-limit violations: **none**.
- Released-rack hold position span: **9.146 × 10⁻⁹ m**.
- Portable model SHA-256: `86539e0e41ca4219cbf6ef47d76f7f8d4e57048b6b66da9d31b32428eba2994d`.
- Trace SHA-256: `8a9c1a2ae9214b6d1f8b0cd1ea0221f3de308f91c2fd288cfc24bf8f1881d08d`.

This is a new run, not the author's earlier restored-final-state report. Machine/room context stays static; it is not a whole-lab workflow or loose-slide retention test.

## Regression and portability checks

- **8/8** `test_lab_rail_loop` integration guards passed against the fresh report.
- **12/12** equipment-access failure guards, Nori posture and machine-glazing tests passed in the separate MuJoCo 3.12.0 environment. The nominal six full access cycles were not rerun as part of this packaging pass.
- Main XMLs and controller startup compile/run in the portable copy.
- A clean local Git clone of commit `091cfd7` restored all three compressed files, compiled all three main models and initialized the live controller successfully. No author-specific mesh path was needed. This checks clone portability, not a fresh operating-system dependency installation.
- All non-path XML parameters, referenced resource bytes and 420 numerical model arrays per scene are compared with the author copy. Resource path buffers and derived convex-hull representations are excluded from bitwise array comparisons and recorded explicitly.
- CAD/trace gzip archives are decompressed and SHA-256 checked.
- README image/file links are checked locally; actual rendered station/asset images are visually reviewed.
- Common token/private-key patterns were scanned without printing candidate secrets. No such matches were found; this is not a comprehensive security audit.

See [portability-validation.json](portability-validation.json), [asset-file-manifest.json](asset-file-manifest.json), [asset-catalog.json](asset-catalog.json), [room-asset-catalog.json](room-asset-catalog.json), and the root `rail_loop_lab_validation.json`.

The original historical video/review reports in the snapshot may refer to earlier hashes. They are provenance, not evidence of the new packaged run or a complete lab. Use the current report and documented test entry points.

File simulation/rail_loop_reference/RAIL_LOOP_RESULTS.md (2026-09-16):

# Moving-Rail Closed Loop

PASS: eleven loaded transfers, visiting all eleven containers and returning the rack to container 1. The carriage traveled from -60.00 to 210.00 mm, ending within 0.015 mm of its start.

## Scope of the Fix

Unlike the previous parked-carriage demonstration, the linear actuator is now commanded throughout transfers along both sides. It uses the full EXISTING MODELED stroke of 270 mm (-60 to +210 mm). The physical rail mesh is about 600 mm long; this does not prove that the carriage can use that whole extrusion. Joint/control/effort limits are unchanged. The source URDF limits rail speed to 0.1 m/s; this planner requests at most 0.02 m/s.

The far-side transition passes above the rail at a verified height; the near-end transition goes around the end. This is a closed operational route, NOT a continuous 360-degree perimeter orbit around both physical rail ends. A literal full-extrusion traversal requires verified hardware stroke and a new reach/clearance check. No physical robot or actuator was operated.

## Results

- Measured peak carriage speed: 19.63 mm/s.
- Minimum rack-bottom clearance above rail during overflight: 50.97 mm.
- Minimum rack-bottom clearance above jar rims during transit: 41.07 mm.
- Maximum seated lateral error: 0.522 mm.
- Maximum relative grasp slip: 1.771 mm.
- Rack/rail contact: 0.000 N.
- Joint-limit violations: [].
- Simulated duration: 313.25 s.

Each transfer verifies grasp settling, a short lift probe, clearance, destination support, release and retreat. The rack remains a free body with no attachment or per-hop reset. The added rail collision box conservatively covers the full rail-mesh bounds and interacts with rack geometry. A separate negative-control test puts the rack into that box to confirm collision detection.

The eleven containers remain on the same bench with unchanged dimensions, 145 g rack payload, 25.4 mm risers, and +/-1.5 Nm arm torque caps. Original parked-carriage tests remain intact. The room and adjacent machines in the video are visual context, not collision-certified. This is a nominal dry reference-control simulation, not a trained policy, hardware reliability study or loose-slide/fluid validation.

## Reproduce

Run with the lerobot Python environment from this directory, in order:

    python rail_loop.py --screen
    python rail_loop.py
    python -m unittest test_rail_loop -v
    python render_lab_row.py rail_loop

Files: rail_loop_layout.json has all lab-world locations and local frame orientations. rail_loop_controller.py is the generated, auditable isolated controller. rail_loop_trace.json contains the measured state history. rail_loop_results.png shows the measured path and carriage travel. rail_loop_review.mp4 shows the full route at 4x speed, with both cameras and measured carriage position.

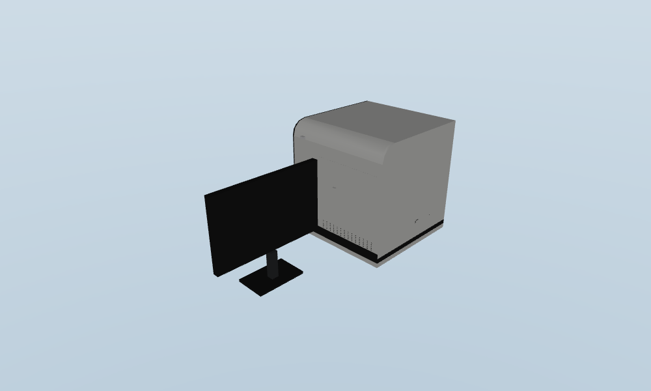
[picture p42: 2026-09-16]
simulation/docs/images/s60-qa-225.png

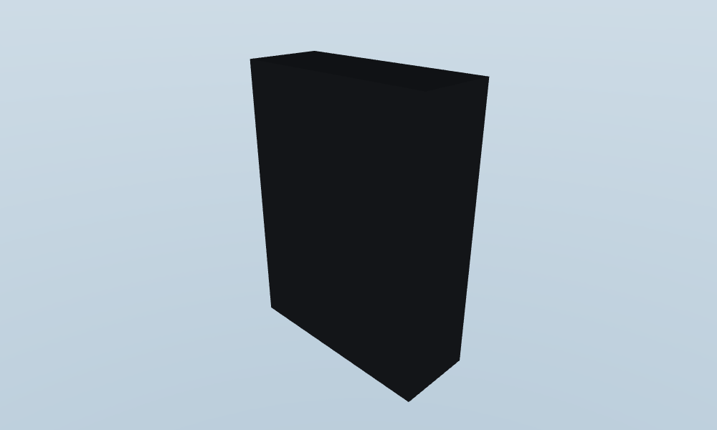
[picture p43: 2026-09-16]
simulation/docs/images/output_magazine-qa-315.png

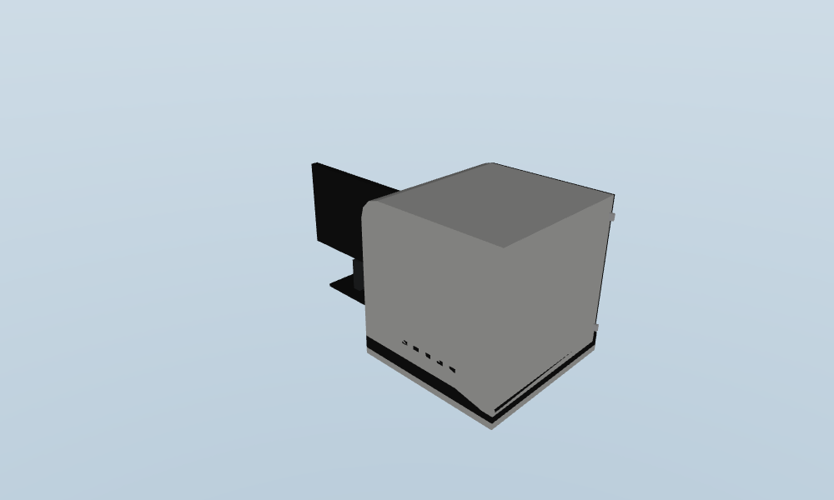
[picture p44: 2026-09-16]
simulation/docs/images/s60-qa-315.png

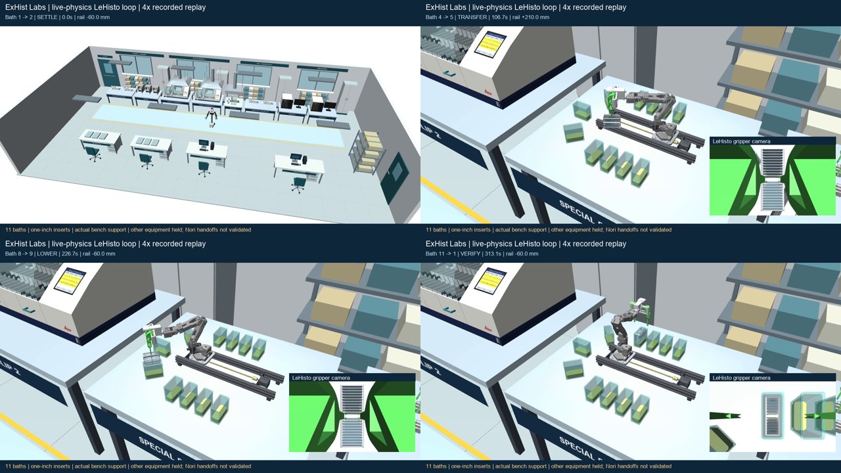
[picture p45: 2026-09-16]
simulation/rail_loop_lab_video_qa.jpg

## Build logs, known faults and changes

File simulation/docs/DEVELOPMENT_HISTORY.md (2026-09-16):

# ExHist Labs - CAD layout and physics-readiness workbench

The lab is assembled from the user's Fusion designs. **Full-lab physical handling is not yet validated.**

## Moving-rail LeHisto loop in the complete lab — current launch

`launch.ps1` (or `launch.ps1 -LeHistoLoop`) opens the complete lab with the live
special-staining contact loop. It starts paused: SPACE runs/pauses, L focuses
LeHisto, O shows the whole room, and 1–8 select stations. `-Hold` retains the
previous read-only readiness view; `-Access`, `-Mobility`, and `-Preview` remain.

The imported eleven-bath route is 1→2→…→11→1. The carriage uses its original
modeled −60 to +210 mm stroke; the far-side transfer crosses above the extrusion.
This is not a 360-degree path around both ends of the physical rail. The rack
is a 145 g free body; the unchanged gripper physically grips it above the
25.4 mm inserts. Original limits and failure guards are retained.

`exhist_rail_loop.xml` includes the entire current lab, transparent machine
lids, canopy and raised Nori inspection posture. The LeHisto station runs live
MuJoCo contacts; other robots and equipment remain held visual context, not
coupled dynamics. Its support uses the bounded actual tabletop and room floor,
not an infinite bench-height plane. This does not validate Nori handoffs,
other-machine contacts, fluids, loose slides or physical hardware.

The pinned source lives in `rail_loop_reference`; the previous eleven-bath
parked-carriage evidence and historical first-pass film are preserved. The
canonical operational layout also uses the new bath transforms on rebuild.
Run `integrate_rail_loop.py` with the Nori environment to refresh the import.
Run `lab_rail_loop.py --validate` with the existing lerobot environment to
repeat all eleven transfers. Current new evidence: `rail_loop_lab_validation.json`.
The completed integration and limitations are summarized in `LAB_RAIL_LOOP_RESULTS.md`;
the new 80-second review is `ExHist-Live-LeHisto-Rail-Loop.mp4`.

The older sections below describe historical development stages; they do not
override current contact/stability reports or unlock full-lab transfers.

## Equipment access / canopy / chest height — 2026-09-15

The special-staining station now has its own open-bottom canopy (1080 x 760 mm,
underside 1700 mm). It is concept geometry, not a fume-containment or ventilation
design. Bench height stays 800 mm. Nori's review IK now prefers a higher lift
posture (example: 430 mm lift / 946 mm shoulder height) and solves **each actual
port height** instead of adding a height offset after IK. This prevents the old
offset method from exceeding the CAD 700 mm lift limit. Low folder poses remain
task-dependent. Full review regression passes with the existing guard retained.

`equipment_access.py` is a separate **actual-arm, fixed-dock development test**.
It supports the Quincy hinge, S60 slide and four Leica drawer interfaces using
their imported CAD joint limits. Only Nori's arm, lift and claw have controls;
equipment motion comes from contact. No door/drawer motor, weld, mocap or runtime
pose assignment is used. Approach, bilateral-force acquisition, paced opening,
hold, closing, release and retreat states stop on slip, contact loss, torque
saturation, collision, jam, unreachable pose or timeout. Failed states continue
physics for at least 0.5 s. Negative tests cannot count as successful access.

The completed nominal contact cycles and current source hashes are recorded in
`ACCESS_VALIDATION.md` and `access_*_validation.json`. Reproduce with
`python access_suite.py`; inspect with `launch.ps1 -Access quincy` (or `s60`,
`st_load`, `st_unload`, `cv_load`, `ts_drawer`). The separate fixed-dock test does
not unlock the full-lab transfer workflow: loaded extraction, insertion,
navigation and exhaustive cabinet/interior collisions are still separate work.

The unchanged left claw now uses 4 mm axial/distal-width CAD contact cells rather
than one hull that fills its hooked profile. Within-cell concavities remain
conservative. Only proximal gear/socket and nested lift-proxy overlaps are
exempted from internal contact; external finger contacts remain enabled.
Contact inspection showed the old 44 mm-clear drawer pull touching
a finger at its mounting leg. The v02 pull concept is 82 x 33 x 10 mm with 66 mm
clear width and 3.3 mm mounting bores. All eight simulated pulls use it; four
separate native Fusion solids and STEP export are in `ExHist-Robot-Drawer-Pulls-v02.*`.
Original machine designs/v01 exports were not overwritten. Fasteners, mounting
strength, grip robustness and manufacturer approval remain unvalidated.

The access fixture fixes the chassis (not wheel/docking validation), uses a
provisional 150 N lift limit, imported 4 Nm arm limits, 0.5 Nm claw limit, 2 N
drawer friction, 1.5 kg drawer mass and estimated door dynamics. Detailed fixed
machine cavities, all internal collisions, latches and seals are incomplete.
Nothing here authorizes hardware operation or certifies a physical grip.

Run `python equipment_access.py --kind quincy --view` for the first isolated
attempt. Other kinds: `s60`, `st_load`, `st_unload`, `cv_load`, `ts_drawer`.
`python -m unittest test_equipment_access -v` checks passivity, missed-grip/jam
failure behavior, unchanged effort caps, the canopy and pull geometry. These
safety-test passes must not be reported as successful opening/closing.

`special_canopy_nori_height.png` and `nori_height_review.json` show the layout and
posture measurements. The default lab viewer still stops at unvalidated access.

## One-inch 24-slide container risers

All 11 review containers now contain a separate passive **25.4 mm** insert.
The canonical jar builder and existing operational jars include the same insert.
Rack seating, Nori transfer targets and the five active LeHisto bath paths are
raised by exactly 25.4 mm. The grip center moves from 0.8 mm below the rim to
24.6 mm above it. Lateral rail travel/reach is unchanged.

`jar_riser.py` defines a 94 x 40 x 25.4 mm block with 6.2 mm clipped corners,
fitting the conservative jar cavity while supporting the rack-base footprint.
Each insert is a free body with gravity/contact support, no actuator or weld.
Mass is provisionally 120 g. Original Fusion jar/rack designs are not overwritten.
STL (millimetres), editable OpenSCAD and mesh JSON are in `assets/rack24_riser*`.
Material, chemical compatibility and fabrication tolerances remain unvalidated.
The raised slides reduce available immersion depth by 25.4 mm; reagent levels
and block displacement need checking before physical use. No fluid behavior or
reagent fill setting has been silently changed.

`python -m unittest test_jar_riser test_review_corrections -v` verifies insert
height/count, fit, passive gravity support (including a no-insert control),
raised target frames and the updated arm reach paths.

## Screenshot correction pass — 2026-09-15

The old three-minute film is superseded, not evidence of successful transfers.
`launch-first-pass.ps1` now runs a **guarded review**: it stops before unvalidated
equipment access. SPACE cannot bypass that hold; R resets the review. Neither
incubator nor scanner doors move from workflow timers anymore. Their existing
CAD handle locations are explicit sites, but a contact-driven opening/closing
controller is still required. Do not interpret the hold as completed integration.

Corrected in the review model (source Fusion files unchanged):

- 24-rack T-bar frame and 90-degree carrier orientation, based on the actual CAD
  and local real-world approach/YOLO pre-close recordings; original fingers retained.
- Rack bases and QC blocks placed inside tabletop support footprints; no elevated
  placeholder slide on an empty LeHisto gripper. QC block base gap is effectively zero.
- Unused Nori arms relax downward. Scanner carriers, CV output magazines, and
  closed folders have left-arm candidate poses; those grips are not contact-certified.
- Coverslipper enclosure visible by default; X deliberately selects cutaway.
- Eleven actual perpendicular jars fit the special-stain table. Only the central
  five (4–8) have verified seated/rim-clearing IK paths within the exported 270 mm
  rail stroke. The six darker outer jars are spares, not claimed reachable baths.
  The five-bath candidate choreography keeps the rack on its upper-handle frame.

`rack24_contact_check.py` separately tests the real 20 x 2 x 3 mm T-bar extents
with the original grooves, gravity and a free rack body. It sweeps provisional
0.8/2/4 N jaw-force limits at an assumed 145 g loaded mass, and checks deliberately
weak and 90-degree-misaligned grasps. It is a Cartesian fixture, not Nori; its
conservative lower-rack envelope and lumped mass do not validate loose slides.
The release/drop criterion is required as well as the lift/hold criterion.
At the current fixture settings, the 2 N case passes lift/hold/release; the 0.8 N
and 4 N cases lift but fail release. Therefore this sweep does **not** establish
a robust handling range or a hardware servo setting. Both negative controls fail
to acquire a grasp, as intended. These limitations are kept in the saved report.

Remaining: contact-driven incubator/scanner access; actual shelf/cassette insertion;
CV output extraction by Nori; complete CV magazine slot geometry; populated-CV-to-S60
slide exchange; loaded left-hand carrier/folder grasp and retention. No second Nori
or speculative replacement gripper has been installed. Scanner depth remains provisional.

Checks: `python -m unittest test_review_corrections test_first_pass test_workflow -v`.
`first_pass.py --check` checks the guarded stop. An explicit `--storyboard` bypasses
access holds **only for candidate-motion inspection**, never physical operation.
The film renderer requires `--storyboard` and writes a differently named,
explicitly unvalidated movie, preserving the historical film.

## First-pass workflow review (new)

Historical milestone below; superseded by the guarded correction pass above.
`ExHist-First-Pass-Three-Minute.mp4` is the 180-second narrated-by-caption review,
based on the previous `Leica-Workstation-Three-Minute-v3.mp4` CAD choreography.
The original `launch.ps1` still defaults to the physics-readiness hold.

The review completes four batches / 36 slides / 25 station transfers. Both Leica
workstations now display the actual bath route, supported TS transfer, individual
slide extraction/rotation/coverslip/output, and empty-rack return. The later snap
handles are registered onto the older film rack. Nori turns in the aisle, faces
the equipment at handoff, and carries review payloads at its original groove
frame. LeHisto robots perform representative slide-handling motions.

Folder finishing now uses the actual 20-place cardboard tray and both CAD flaps.
Nori places the assigned slides into individual slots, closes the left and right
flaps, then transfers each closed folder to a distinct position on the existing
General Work bench, relabeled FINISHED SLIDE FOLDERS. Completion is counted only
after this delivery. A partly populated case folder may close once every slide
assigned to that case is seated; unused slots do not need to be filled.
Nori owns the loading/closing task exclusively, so it cannot simultaneously run
another transfer. The current LeHisto placement could not meet all tested flat
slot poses, so this operation is assigned to Nori without changing the grippers.
Slot geometry comes from the CAD (77 x 27 mm recesses; 75 x 24.95 mm slide visuals).
Cardboard crease axes, flat staging-point supply, edge pinch and contact/retention
forces remain first-pass assumptions. `folder_finish.py` contains the geometry
and sequencing; `review_folders.py` renders the filled/closing/closed/finished views.
The folder work positions leave clearance to the rear rails; block-QC samples
are moved forward within the same bench in this review copy. Run
`python first_pass.py --folder-review --speed 2` to start at the finishing segment.

Controls: SPACE pause, R restart, X machine cutaway, 1-8 station views, O overview,
9 finished-folder bench, T follow Nori, V/B/N head left/right/wide, M oblique head interaction camera,
+/- playback speed, F inject scanner fault, C recover.

This is deliberately **not** a physical-transfer success claim: machine visuals
replay rigid CAD transforms; the old machine joint graph is retained at its
source pose, not dynamically driven. Nori/LeHisto and access-joint motion is
kinematic; wheel rotation is visual odometry. No contact/grip-force validation is
inferred from an attached visual payload. Incubator/scanner insertion, passive
drawer forces, special-rack re-racking and scanner/folder carrier exchanges are
still abstractions. Front staging ports are provisional. The cosmetic flexible
mountant hose is omitted from the rigid-only playback. Original CAD and the
contact-only development benches remain unchanged.

Rebuild: `python build_first_pass.py`; validate: `python test_first_pass.py`;
render the film: `python film_first_pass.py`. The builder/playback reference the
earlier local Leica film project through `first_pass_assets.json`; this is not yet
a portable standalone package. The first-pass output is `exhist_first_pass.xml`;
`exhist_operational.xml` and its physics-readiness behavior are preserved.
`first_pass_validation.json` records the regression run; interactive session
progress is kept separately in `first_pass_live.json`.

Regression coverage: the full review, 24 baths per routine batch, 8/6/12/10
covered-slide inventories, 25 paired visual handoffs, equipment-facing heading,
active joint limits, near-pick pose alignment, pause, reset and camera selection.
The original workflow fault/recovery and 14 docking/readiness tests also pass.

Newest: `arm_transfer.py --front` performs the slide transfer with Nori facing
the table, an approved provisional force-limited lift motor, and three fixed
head-mounted camera views. `head_camera_interactions.png` shows sampled object
interactions. `equipment_dock_bench.py` tests wheel-driven facing/stopped docking.
`simulation_parameters.json` clearly separates assumed values from hardware
specifications. These primitives are not yet one connected full-lab workflow.

Latest: `arm_transfer.py` completes an actual Nori-arm, contact-only slide
pick/lift/carry/place/release test. It uses development guide slots and an explicit
lift brake, not a completed machine-to-machine workflow. Run
`python -m unittest test_arm_transfer -v` for eight additional groups (25 total
with previous readiness tests). Matching CAD staining jars are now restored from
the `Staining Jar` body in `Slide Rack v13`. See the newest readiness-report section.

New: `launch.ps1 -Mobility` runs a separate wheel-driven Nori development test
(forward, body turn, forward, stop). It uses an explicit lift test brake and
assumed chassis/caster/wheel parameters. The passive-drawer contact test detects
slip and force faults but does not yet complete opening/closing. Run
`python -m unittest test_mobile_drawer -v` with the project runtime for six
regressions. See the new integration section in PHYSICS_READINESS.md for scope.

`launch.ps1` now opens a read-only **PHYSICS READINESS HOLD**. No passive objects or robots animate and no workflow completes. `launch.ps1 -Preview` explicitly enables the old **ANIMATION ONLY** workflow.

Start with [PHYSICS_READINESS.md](PHYSICS_READINESS.md) for current findings, CAD changes needed, seven regression tests, and the separate contact-only slide-grip bench. That report supersedes the historical first-layout notes below. Contact tests do not establish Nori arm, wheel, rack retention or bucket-insertion validity.

Latest correction: keep the physically tested original upper handle/lower slide grooves. `groove_bench.py` tests those grooves without added pads; `gripper_mass_model.json` replaces the erroneous all-steel mass with an explicit ~257 g construction estimate. Eight passive drawer-pull concepts and a separate Fusion/STEP CAD export are added. See the correction at the top of the readiness report.

## Historical first-layout milestone (not current physics status)

## Included
- Two LeHisto sorters, three Quincy 10GC ovens, two complete Leica ST5020/CV5030 workstations.
- One special-stain LeHisto with a provisional open reagent-bucket lane.
- Two send-out LeHistos, two actual 20-place slide folders, and provisional block QC samples.
- Two NanoZoomer S60 assemblies with their CAD monitors.
- Actual Leica racks and 24-slide racks.
- Nori A3 with the original 22 joints and three mimic constraints, plus three planar preview joints.
- Eight tables, named docking sites and handoff sites.

## Viewer
Run launch.ps1 in PowerShell. SPACE toggles the scripted station tour.
Keys 1-8 focus a station and place Nori in the aisle opposite it. O returns to the overview.
Use the mouse to orbit and zoom. The tour uses prescribed base positions and mj_forward.
It is a kinematic inspection preview, not autonomous navigation or physical wheel simulation.

## Files
- exhist.xml: self-contained MuJoCo model with relative asset paths.
- build_scene.py: reproducible CAD mesh conversion and table placement.
- run_lab.py: inspection viewer, preview rendering and validation.
- assets/*.json: body geometry, CAD colors and source names exported from Fusion.
- assets/*.obj: generated visual meshes; asset instances reuse these meshes.
- layout.json: dimensions, placements, station sites and assumptions.
- validation.json: compile and sampled straight-aisle geometry check.
- overview.png, sorting.png, sendout.png, imaging.png: actual MuJoCo renders.

## Rebuild and verify
Use the existing Python runtime:
C:/Users/Owner/Documents/Nori/.venv/Scripts/python.exe
Run build_scene.py, then run_lab.py --check --render.

## Current limits
Equipment and LeHisto geometry is static in this milestone. The CAD joints have not been exported.
The original Nori installation is untouched; its meshes are copied into this project.
Machine envelope colliders are conservative solid boxes, not suitable for rack insertion.
Table height (0.80 m), table placement and dock sites are provisional. The row is 14.85 m long.
The bucket geometry and block QC samples are placeholders; no reagent chemistry is simulated.
The S60 source is NanoZoomer-S60-branding-v05.f3d, based on door-fit-v04.
Front branding is CAD geometry approximated from the user's photo and shared by both simulated scanners.
The scanner's internal cassette depth remains provisional.
The Leica source is the Mechanical QC v2 workstation. The folder is Cardboard Slide Folder - 20 Place v1.
The Leica rack asset has 28 slides. The 24-slide rack is the actual Slide Rack v13 CAD body.
Validation checks compilation, preserved mimic constraints, site presence and 80 aisle positions.
It does not establish docking feasibility, grasp success, device behavior, throughput, or sim-to-real performance.
Next: export articulation and precise contact surfaces, measure handoff poses, and implement one rack transfer.

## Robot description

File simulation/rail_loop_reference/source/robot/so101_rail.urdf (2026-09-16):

<?xml version='1.0' encoding='utf-8'?>
<robot name="so101_rail">
  <mujoco>
    <compiler meshdir="meshes/arm" />
  </mujoco>
  <link name="world" />
  <joint name="rail_travel" type="prismatic">
    <parent link="world" />
    <child link="base_link" />
    <origin xyz="0 0 0" rpy="0 0 0" />
    <axis xyz="0 1 0" />
    <limit lower="-0.06" upper="0.21" effort="200" velocity="0.1" />
  </joint>
  <link name="base_link">
    <inertial>
      <origin xyz="-7.395983749131527e-05 0.018688778123587116 0.031975817456183726" rpy="0 0 0" />
      <mass value="0.2092095548721987" />
      <inertia ixx="0.000199" iyy="0.000196" izz="0.000203" ixy="1e-06" iyz="-1e-05" ixz="0.0" />
    </inertial>
    <visual>
      <origin xyz="0 0 0" rpy="0 0 0" />
      <geometry>
        <mesh filename="meshes/arm/base_link.stl" scale="0.001 0.001 0.001" />
      </geometry>
      <material name="silver" />
    </visual>
    <collision>
      <origin xyz="0 0 0" rpy="0 0 0" />
      <geometry>
        <mesh filename="meshes/arm/base_link.stl" scale="0.001 0.001 0.001" />
      </geometry>
    </collision>
  </link>
  <link name="link1_1">
    <inertial>
      <origin xyz="-6.74951590711253e-05 -0.030490405697529033 0.053766555610065915" rpy="0 0 0" />
      <mass value="0.24184654503223657" />
      <inertia ixx="0.000195" iyy="0.000199" izz="9.5e-05" ixy="1e-06" iyz="1.6e-05" ixz="-2e-06" />
    </inertial>
    <visual>
      <origin xyz="9.9e-05 0.007243 -0.027983" rpy="0 0 0" />
      <geometry>
        <mesh filename="meshes/arm/link1_1.stl" scale="0.001 0.001 0.001" />
      </geometry>
      <material name="silver" />
    </visual>
    <collision>
      <origin xyz="9.9e-05 0.007243 -0.027983" rpy="0 0 0" />
      <geometry>
        <mesh filename="meshes/arm/link1_1.stl" scale="0.001 0.001 0.001" />
      </geometry>
    </collision>
  </link>
  <link name="link2_1">
    <inertial>
      <origin xyz="-0.018388577871412994 0.06261038358877268 0.0010120440807449838" rpy="0 0 0" />
      <mass value="0.98611438366224" />
      <inertia ixx="0.001336" iyy="0.000432" izz="0.001637" ixy="1.3e-05" iyz="-3.7e-05" ixz="-1e-06" />
    </inertial>
    <visual>
      <origin xyz="-0.020792 0.038556 -0.11936" rpy="0 0 0" />
      <geometry>
        <mesh filename="meshes/arm/link2_1.stl" scale="0.001 0.001 0.001" />
      </geometry>
      <material name="silver" />
    </visual>
    <collision>
      <origin xyz="-0.020792 0.038556 -0.11936" rpy="0 0 0" />
      <geometry>
        <mesh filename="meshes/arm/link2_1.stl" scale="0.001 0.001 0.001" />
      </geometry>
    </collision>
  </link>
  <link name="link3_1">
    <inertial>
      <origin xyz="-0.017751520535904237 -0.06544031690248904 -0.0001729613192295032" rpy="0 0 0" />
      <mass value="0.9031154796125306" />
      <inertia ixx="0.001194" iyy="0.000364" izz="0.00144" ixy="1.5e-05" iyz="1.4e-05" ixz="-2e-06" />
    </inertial>
    <visual>
      <origin xyz="-0.022302 -0.073879 -0.148777" rpy="0 0 0" />
      <geometry>
        <mesh filename="meshes/arm/link3_1.stl" scale="0.001 0.001 0.001" />
      </geometry>
      <material name="silver" />
    </visual>
    <collision>
      <origin xyz="-0.022302 -0.073879 -0.148777" rpy="0 0 0" />
      <geometry>
        <mesh filename="meshes/arm/link3_1.stl" scale="0.001 0.001 0.001" />
      </geometry>
    </collision>
  </link>
  <link name="link4_1">
    <inertial>
      <origin xyz="-0.014388616159181473 -0.028802697165152366 -0.00020561897946119734" rpy="0 0 0" />
      <mass value="0.31773533805976817" />
      <inertia ixx="0.000138" iyy="0.000153" izz="0.000239" ixy="2.5e-05" iyz="0.0" ixz="-1e-06" />
    </inertial>
    <visual>
      <origin xyz="-0.024382 0.060582 -0.152897" rpy="0 0 0" />
      <geometry>
        <mesh filename="meshes/arm/link4_1.stl" scale="0.001 0.001 0.001" />
      </geometry>
      <material name="silver" />
    </visual>
    <collision>
      <origin xyz="-0.024382 0.060582 -0.152897" rpy="0 0 0" />
      <geometry>
        <mesh filename="meshes/arm/link4_1.stl" scale="0.001 0.001 0.001" />
      </geometry>
    </collision>
  </link>
  <link name="link5_1">
    <inertial>
      <origin xyz="-0.0005839285183169068 -0.04153912948671028 0.01505583353882603" rpy="0 0 0" />
      <mass value="0.5561721109318601" />
      <inertia ixx="0.000579" iyy="0.000983" izz="0.000737" ixy="1e-06" iyz="-8.4e-05" ixz="-5e-06" />
    </inertial>
    <visual>
      <origin xyz="-0.007062 0.120627 -0.152066" rpy="0 0 0" />
      <geometry>
        <mesh filename="meshes/arm/link5_1.stl" scale="0.001 0.001 0.001" />
      </geometry>
      <material name="silver" />
    </visual>
    <collision>
      <origin xyz="-0.007062 0.120627 -0.152066" rpy="0 0 0" />
      <geometry>
        <mesh filename="meshes/arm/link5_1.stl" scale="0.001 0.001 0.001" />
      </geometry>
    </collision>
  </link>
  <joint name="base_link_to_link1" type="revolute">
    <origin xyz="-9.9e-05 -0.007243 0.027983" rpy="0 0 0" />
    <parent link="base_link" />
    <child link="link1_1" />
    <axis xyz="-0.0 -0.008727 0.999962" />
    <limit lower="-2.094395" upper="2.094395" effort="1.5" velocity="5.236" />
    <dynamics damping="0.1" friction="0.05" />
    <safety_controller soft_lower_limit="-2.044" soft_upper_limit="2.044" k_position="100" k_velocity="10" />
  </joint>
  <joint name="link1_to_link2" type="revolute">
    <origin xyz="0.020891 -0.031313 0.091377" rpy="0 0 0" />
    <parent link="link1_1" />
    <child link="link2_1" />
    <axis xyz="-0.999962 -0.008726 -7.6e-05" />
    <limit lower="-3.228859" upper="0.174533" effort="1.5" velocity="5.236" />
    <dynamics damping="0.1" friction="0.05" />
    <safety_controller soft_lower_limit="-3.179" soft_upper_limit="0.125" k_position="100" k_velocity="10" />
  </joint>
  <joint name="link2_to_link3" type="revolute">
    <origin xyz="0.00151 0.112435 0.029417" rpy="0 0 0" />
    <parent link="link2_1" />
    <child link="link3_1" />
    <axis xyz="-0.999924 -0.00865 -0.008802" />
    <limit lower="0.0" upper="3.316126" effort="1.5" velocity="5.236" />
    <dynamics damping="0.1" friction="0.05" />
    <safety_controller soft_lower_limit="0.05" soft_upper_limit="3.266" k_position="100" k_velocity="10" />
  </joint>
  <joint name="link3_to_link4" type="revolute">
    <origin xyz="0.00208 -0.134461 0.00412" rpy="0 0 0" />
    <parent link="link3_1" />
    <child link="link4_1" />
    <axis xyz="-0.999848 0.000153 -0.017451" />
    <limit lower="-1.658063" upper="1.658063" effort="1.5" velocity="5.236" />
    <dynamics damping="0.1" friction="0.05" />
    <safety_controller soft_lower_limit="-1.608" soft_upper_limit="1.608" k_position="100" k_velocity="10" />
  </joint>
  <joint name="link4_to_link5" type="revolute">
    <origin xyz="-0.01732 -0.060045 -0.000831" rpy="0 0 0" />
    <parent link="link4_1" />
    <child link="link5_1" />
    <axis xyz="-1e-06 0.999961 0.008803" />
    <limit lower="-4.276057" upper="1.570796" effort="1.5" velocity="5.236" />
    <dynamics damping="0.1" friction="0.05" />
    <safety_controller soft_lower_limit="-4.226" soft_upper_limit="1.521" k_position="100" k_velocity="10" />
  </joint>
  <link name="tcp_link">
    <inertial>
      <origin xyz="0 0 0" />
      <mass value="1e-6" />
      <inertia ixx="1e-9" iyy="1e-9" izz="1e-9" ixy="0" iyz="0" ixz="0" />
    </inertial>
  </link>
  <joint name="link5_to_tcp" type="fixed">
    <origin xyz="0.0018780289 -0.081250806 -0.10789722" rpy="1.5795974 -0.017502118 -0.00015403437" />
    <parent link="link5_1" />
    <child link="tcp_link" />
  </joint>
</robot>

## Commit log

2026-09-16 Package ExHist lab simulation with portable assets and illustrated run guide
    [00_base_shell.stl, 01_shoulder_pitch_mirrored.stl, 02_shoulder_roll_mirrored.stl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]
2026-09-16 Add selectable 45-degree QC folder cradle with scoped layout checks
    [Folder-Stand-45-Assembly.stl, Folder-Stand-45-backing.stl, Folder-Stand-45-foot_0.stl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]
2026-09-17 Publish upright-rack promo, portable playback, and final QC concept assets
    [Folder-Stand-45-Assembly.stl, Folder-Stand-45-Concept.f3d, Folder-Stand-45-Concept.step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]
2026-09-17 Organize repository into a self-contained simulation bundle and concise landing page
    [00_base_shell.stl, 01_shoulder_pitch_mirrored.stl, 02_shoulder_roll_mirrored.stl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]
2026-09-18 Publish revised lab promo with looping README preview and portable playback
    [base.stl, base_link.stl, campitch.stl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]
